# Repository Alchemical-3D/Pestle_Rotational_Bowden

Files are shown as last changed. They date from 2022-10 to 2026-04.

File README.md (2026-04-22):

<div align="center">

# 🥣 Pestle Rotational Bowden





*The flexible Bowden system designed to fit almost anywhere, while providing rotational movement to support even shorter Bowden assemblies.*

<p align="center">
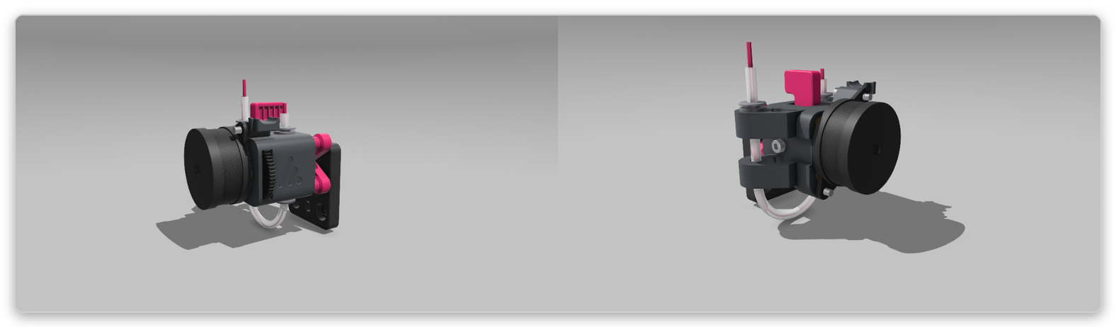
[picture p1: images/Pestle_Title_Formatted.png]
Bowden
  
</p>

**[Join the Discord!](https://discord.gg/aE49DW2xXe)**

</div>

<br>

---

## 📖 Preface

This is the Pestle Rotational Bowden.

The goal of this project is to provide an ultra-lightweight but powerful extruder which rides the X gantry (or anywhere else you wish) while also being able to rotate, allowing the shortest Bowden tube possible. The rotation removes the need for additional bend radii to get to the toolhead by providing a more direct route. 

Initial testing of this unit showed it was able to achieve a Bowden length of approximately <228.6mm, when the stock tube was near 508mm long. That is an improvement of 50%. On top of the PTFE length savings, the more direct filament route results in much lower PA values than traditional Bowden setups, as well as retraction settings which are more in line with Direct Drive. All of these benefits combined create a system that takes the best from each world without sacrificing overall performance.

The concept for this extruder was inspired by the now-defunct Voron Jetpack. We would like to extend a special thanks to the Voron team for their inspiration on this product. Please take a moment if you are not familiar with the Voron project to educate yourself on the hard work they commit to the makerspace: [https://vorondesign.com/](https://vorondesign.com/)

---

<p align="center">
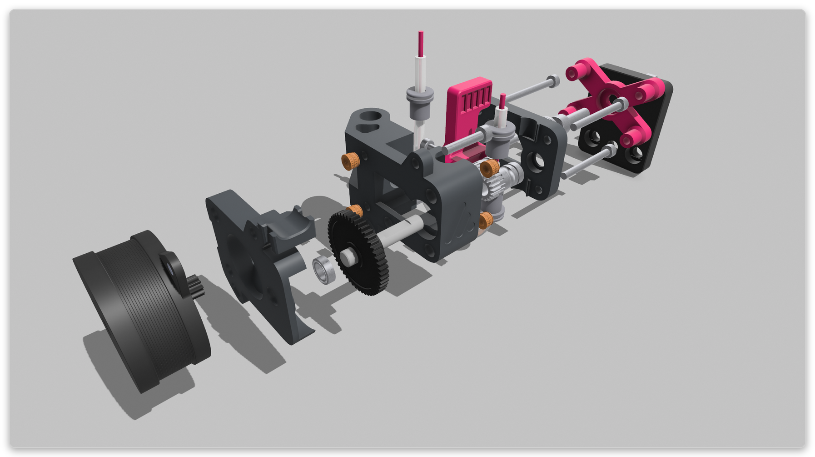
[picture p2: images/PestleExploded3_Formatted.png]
Bowden 2
  
</p>

---

## ⚙️ Print Settings

| Setting | Value |
| :--- | :--- |
| **Materials** | ABS/ASA *(Note: Parts account for shrinkage of ASA & ABS)* |
| **Layer Height** | 0.20 mm |
| **Extrusion Width** | Forced 0.4 mm |
| **Infill Percentage** | 40%+ |
| **Infill Type** | Grid, Honeycomb, Triangle, or Cubic |
| **Top/Bottom Wall Count** | 5 |
| **Perimeter Count** | 4 |

---

## 📋 Bill of Materials (BOM)

> [!NOTE]
> **Affiliate Links**
> Alchemical-3D has affiliate status with most of the links below. Purchases using these links help continue funding of the project. If you wish to configure a Pestle kit through a vendor (KB-3D) instead of sourcing individual parts, use this link [here](https://kb-3d.com/store/extruders-hotends/731-pestle-rotational-bowden-extruder-kit-beta-12-configurable-1670209967306.html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).
>
> *Note: This list is the bare minimum. It is wise to have spare screws, heat sets, etc.*

| QTY | Material | Notes |
| :---: | :--- | :--- |
| **7** | [M3x5x4 Heatsets](https://kb-3d.com/store/inserts-fasteners-adhesives/278-brass-heat-set-threaded-insert-for-plastic-m3x5x4mm.html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) | Angled exterior texture, not straight |
| **1** | [Thrust Bearing](https://kb-3d.com/store/magnets-bearings/696-5mm-x-12mm-x-4mm-thrust-bearing-f5-12m-1645908989939.html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) | 5mm ID x 12mm OD |
| **1** | M3x16mm SHCS | Socket Head Cap Screw |
| **1** | M3x20mm SHCS | Socket Head Cap Screw |
| **2** | M3x30mm SHCS | Socket Head Cap Screw |
| **2** | M3x35mm SHCS | Socket Head Cap Screw |
| **1** | M5x16mm SHCS | Socket Head Cap Screw |
| **1** | M5 Hex Nut | Standard M5 Hex Nut |
| **3** | [PC4-M6 Connector](https://kb-3d.com/store/inserts-fasteners-adhesives/707-push-fit-embedded-bowden-fitting-coupler-175-ecas04-1667064368065.html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) | Pneumatic Bowden Fitting |
| **1** | [BondTech BMG Internals Kit](https://kb-3d.com/store/bondtech/484-bondtech-bmg-extruder-internals-kit-build-your-own-1645151327973.html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) | Clones acceptable |
| **1** | [LDO Nema 14 High Temp Stepper Motor - 9T](https://kb-3d.com/store/stepper-motors-servos/4480-ldo-nema-14-high-temp-stepper-motor-36sth20-1004ahg-9t-for-g2-1640706862009.html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) | Pancake Stepper - Round |
| **1** | [Loctite 222MS Threadlocker](https://kb-3d.com/store/tools-equipment/774-loctite-threadlocker-222ms-low-strength-purple-mil-spec-6ml-1673749510419.html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) | Recommended Optional |

## ⚠️ Important Build Notes
> [!WARNING]
>
> If using **Threadlocker** (Loctite Blue or similar strength), please note that these can damage ASA/ABS when coming into contact. Take care when applying threadlockers to ensure they only contact the metal assembly parts.

> [!CAUTION]
> **Material Warning**
>
> This assembly comes in close proximity to a heated bed and stepper motor.  We do not support issues related to using PLA or other similar materials (PETG, PLA+, etc.).  These are **NOT** suitable to build 3D printer parts out of.

> [!WARNING]
> **Builder Responsibility**
>
> This is an aftermarket engineering project. You are solely responsible for your own safety and the integrity of your equipment when building and operating this system. By utilizing these files and instructions, you accept all liability.

---

## 🛠️ Assembly Guide

If you have questions regarding the location and orientation of each screw, heat set, and part you will require to assemble the Pestle extrusion system, please join the Discord and feel free to ask!

1. Locate each heat set location in the Pestle Extruder assembly; there should be a total of 6 heat sets required for assembly: (3) Main Body, (1) Lever, and (2) Transmission Plate. Heat your soldering iron to an appropriate temperature for the filament being used (near printing temp) and slowly press each heat set in squarely.
   > [!IMPORTANT]
   > The heat set in the main body that secures the lever **MUST** be inserted from the bottom of the body and remain flush with the bottom of the model. If this heat set is inserted from the top or improperly inserted, it may interfere with the lever's function.

2. Locate the (3) PC4-M6 locations. Two of these pieces will be added during assembly; the third can be added at any time. When adding the PC4-M6 fitting to the support arm, ensure it is being pressed in squarely, or the model can split. You may use a wrench or other flat object between the arm braces—place the fitting on a table and push down on it for easier insertion. Brute force may result in broken parts.

3. Insert (1) MR85ZZ bearing (included in the BMG kit) into the Top Plate and Bottom Plate of the extruder. A cutout has been made to allow a press-fit. These parts should be snug, but take care when inserting to keep components square and reduce the risk of cracking the model.

4. Slide (2) 5mm OD / 3mm ID needle bearing assemblies over (1) short 3mm bearing steel rod, and the secondary BMG drive gear over the top of the needle bearings. Snap the gear assembly into the printed Lever housing.

5. Insert (1) thumbscrew spring (included in the BMG kit; set aside the thumbscrew) into the inside of the main body. A recess has been made to house this spring, and once the lever is installed, it will be secure.

6. Verify alignment and use the printed lever arm to compress the spring as you insert it into the main body of the Pestle. Do not bend the main body at the lower supports, or it may break; use the main body section of the spring to pin the lever in place. Once in place, verify the filament path lines up with the teeth on the secondary BMG gear.

7. Slide the BMG primary gear over the BMG 50T 5mm primary drive gear and secure the grub screw to the flat section. A typical installation of the BMG gear sets it almost all the way down the shaft. Insert the back of the BMG drive gear into the bearing previously installed on the transmission plate.

8. Locate and install the transmission plate, Nema 14 stepper, and main body with the geared assemblies all at once. The stepper motor will hold the assembly together as the build continues. Do not worry about setting the stepper adjustments at this point.

9. Slide the top plate and bearing over the main body and gear assembly, and insert the final (2) PC4-M6 fittings between the top plate and the main body. Fittings must be added prior to fastening the top plate.

10. Add an M5x16 BHCS to the Rotational Cross Brace so that the threads stick out away from the top, with a thrust bearing (or shim washers) placed between the head of the bolt and the printed Rotational Cross Brace.

11. Add the rotational cross brace to the top of the Pestle extruder by fitting the (4) posts into the top plate's post holes. Secure the brace using (2) M3x30mm and (2) M3x35mm BHCS screws. The screws will pass through the entire assembly to the transmission plate and main body, respectively.

12. Add an M5 nut to your respective mounting solution and thread the Pestle assembly through it, with a thrust bearing placed between the rotational cross brace and the mounting solution.

13. *(Skip this step if not using PTFE in this manner)* Add PTFE Bowden tubing from the support arm looping under the extruder and into the bottom of the extruder. This acts as the reverse Bowden guide for the filament. Take care not to bend at too steep of an angle and kink the PTFE. If the PTFE is kinked and does not allow filament to pass smoothly, it should be replaced.

14. Add PTFE tubing from the top of the extruder to your toolhead assembly, then review the Pestle Retraction Settings below.

---

## 📏 Retraction Settings

| Setting | Value |
| :--- | :--- |
| **Retraction Distance** | 0.95 mm |
| **Retraction Speed** | 40 mm/s |
| **Detraction Speed** | 45 mm/s |
| **Estimated Pressure Advance** | 0.280 |
| **Estimated Pressure Advance Smooth Time** | 0.035 |

> [!NOTE]
> These settings are intended as a starting point for tuning and do not reflect all system requirements. Individual system needs vary, and your specific use case may require adjustments.

***

> ☕ **Did you find this guide helpful?** 
> 
> My projects are open-source and free for the community. If you've enjoyed my designs and want to support my work, consider [leaving me a tip on Ko-fi](https://ko-fi.com/alchemical3d)! 
>
> 

### [Visit our Discord!](https://discord.gg/aE49DW2xXe)

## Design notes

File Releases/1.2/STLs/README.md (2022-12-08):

# Filename Nomenclature

| Filename | Note |
|---|---|
| \*.stl | Base color |
| [a]\_\*.stl | Accent color |

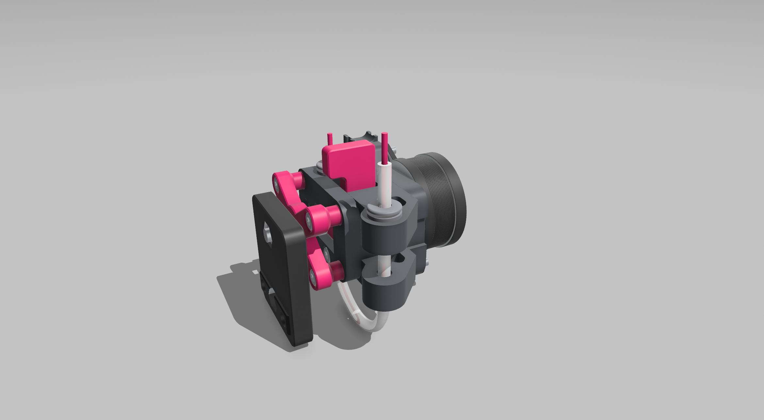
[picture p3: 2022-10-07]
images/Pestle3.png

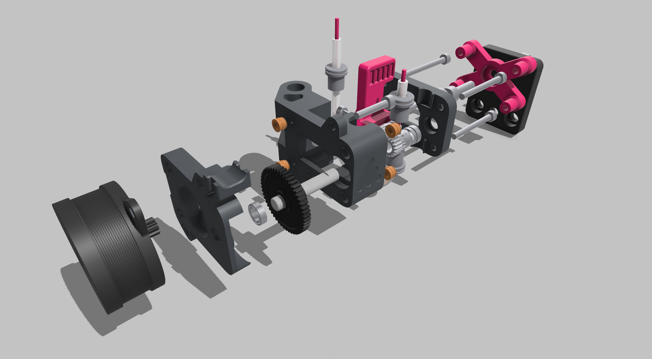
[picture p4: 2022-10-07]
images/PestleExploded3.png

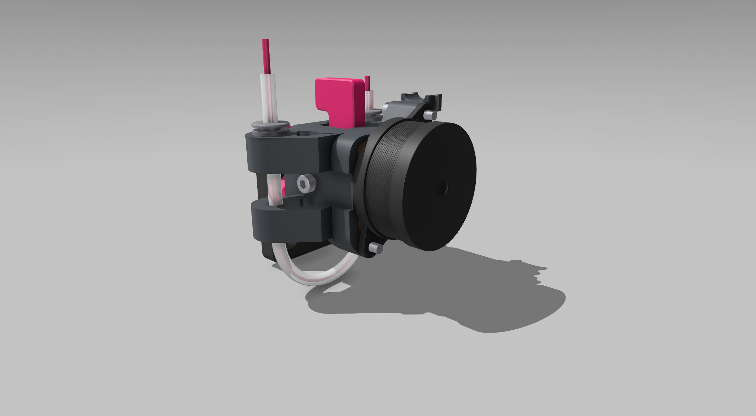
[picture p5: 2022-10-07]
images/Pestle2.png

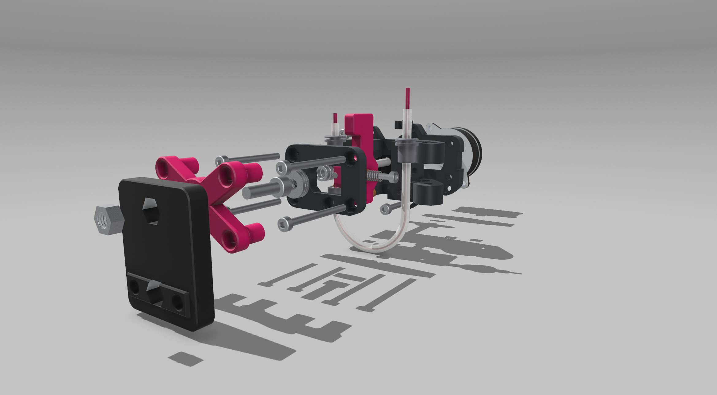
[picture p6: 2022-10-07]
images/PestleExploded5.png

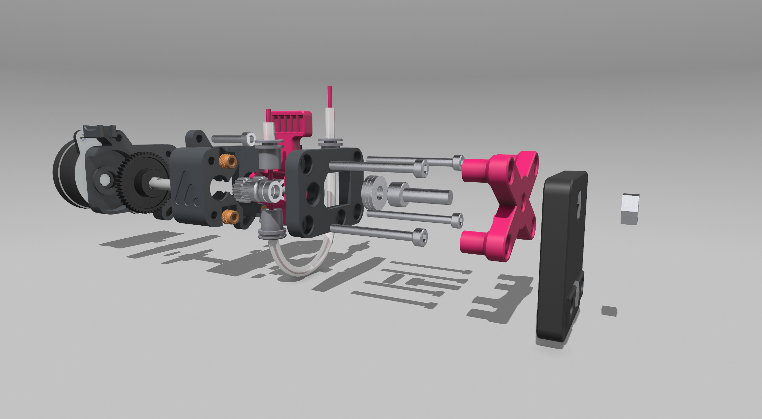
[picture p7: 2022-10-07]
images/PestleExploded1.png

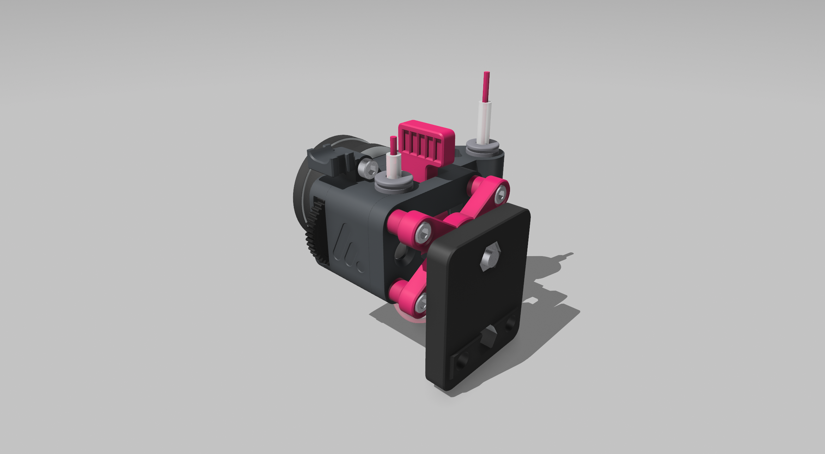
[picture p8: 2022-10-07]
images/Pestle4.png

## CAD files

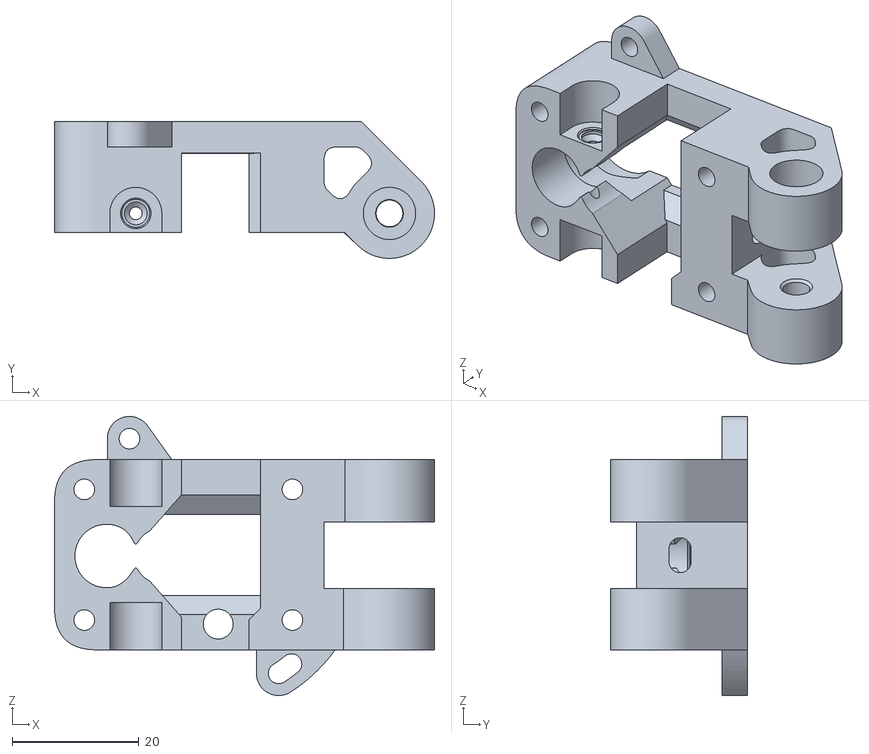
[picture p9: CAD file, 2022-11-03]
Releases/1.2/STLs/pestle_main_body.stl
59.9 x 21.6 x 44.0

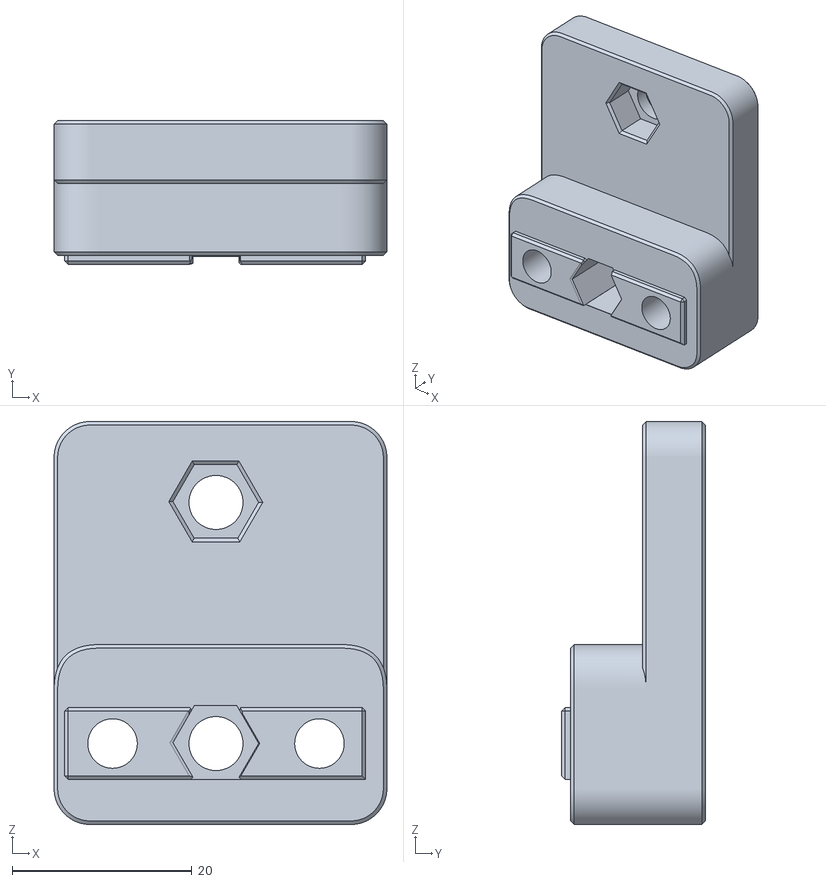
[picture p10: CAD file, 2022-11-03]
Releases/1.2/STLs/pestle_2020_extrusion_mount.stl
37.0 x 16.0 x 44.8

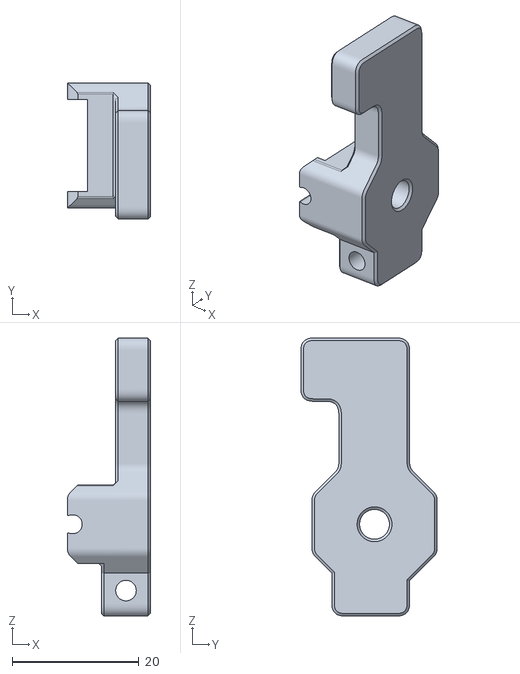
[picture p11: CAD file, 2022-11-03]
Releases/1.2/STLs/[a]_pestle_lever.stl
13.1 x 21.6 x 43.9

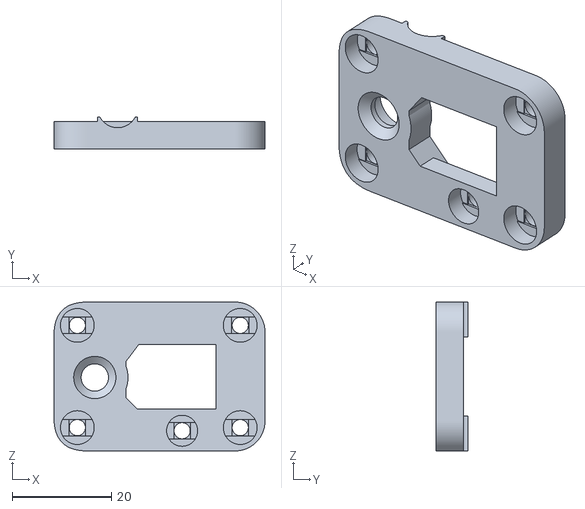
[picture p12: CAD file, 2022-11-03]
Releases/1.2/STLs/pestle_top_plate.stl
42.5 x 6.45 x 30.0

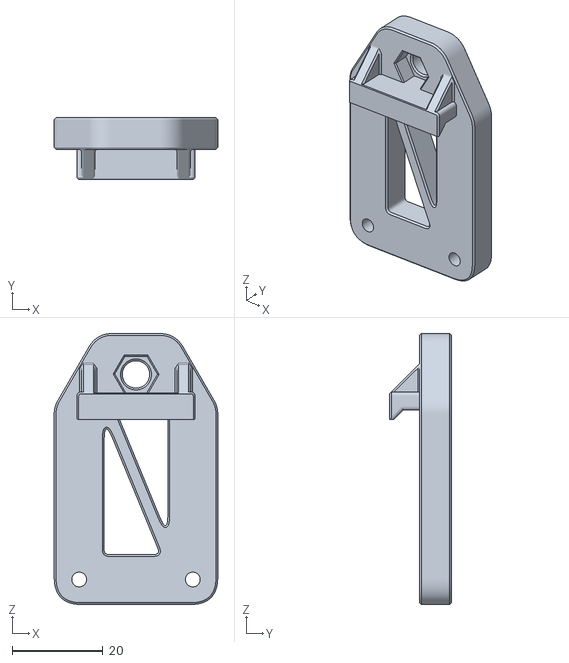
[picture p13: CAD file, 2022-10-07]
Releases/1.2/STLs/pestle_3DFused_gantry_mount.stl
36.0 x 13.6 x 59.6

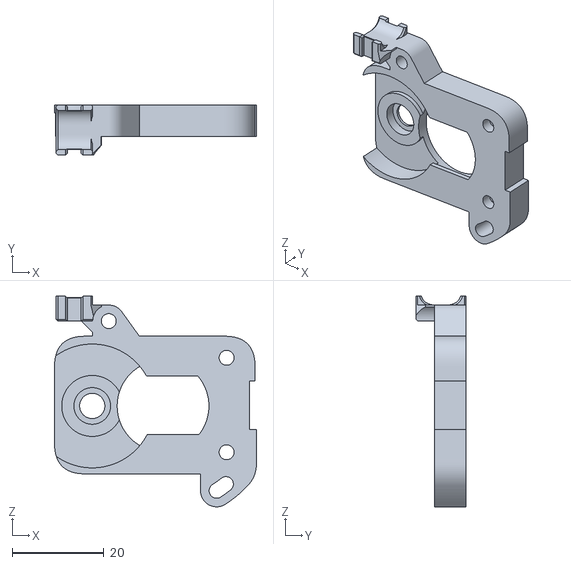
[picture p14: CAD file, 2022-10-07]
Releases/1.2/STLs/pestle_motor_plate.stl
44.0 x 11.0 x 45.9

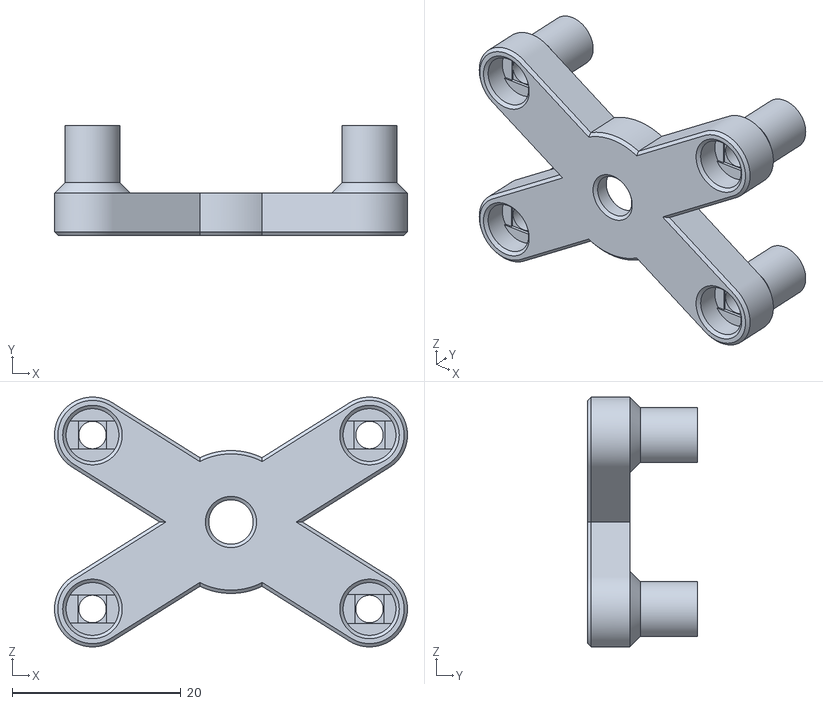
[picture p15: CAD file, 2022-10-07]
Releases/1.2/STLs/[a]_pestle_rotation_brace.stl
41.8 x 13.0 x 29.6

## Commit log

2022-08-25 Version 3.0
    Updates courtesy of Whatthefilament
    https://github.com/whatthefilament
    [Pestel_Rotational_Bowden.step, Pestle_Rotational_Bowden _v3.0 - Gantry Mount.step, Pestle_Rotational_Bowden _v3.0 - Gantry Mount.stl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]
2022-08-26 Printability Tweaks
    [Gantry Mount.step, Gantry Mount.stl, Lever.step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]
2022-09-03 Clearance Fix
    [Main Body -Plate.step, Main Body -Plate.stl, Pestel_Rotational_Bowden_Assembly.step]
2022-09-03 Clearance Update
    [Main Body -Plate.step, Main Body -Plate.stl, Pestel_Rotational_Bowden_Assembly.step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]
2022-10-07 Version Beta_7
    [Pestle parts - 2020_Extrusion_Mount.step, Pestle parts - 2020_Extrusion_Mount.stl, Pestle parts - 3DFused_Gantry_Mount.step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]
2022-11-03 Updated To Rev 1.2
    Greatly improved system tolerances, improved gear meshing, and reduced drive resistances.
    [Pestle_Rev-1.2 parts - 2020_Extrusion_Mount.stl, Pestle_Rev-1.2 parts - 3DFused_Gantry_Mount.stl, Pestle_Rev-1.2 parts - Lever.stl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]
2022-12-08 organizing files
    [Pestle_Rev-1.2 parts - 2020_Extrusion_Mount.step, Pestle_Rev-1.2 parts - 2020_Extrusion_Mount.stl, Pestle_Rev-1.2 parts - 3DFused_Gantry_Mount.step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]
2026-04-21 Update safety warnings in README
    Added warnings about material suitability and builder responsibility.
2026-04-21 Restore important build notes in README
    Reintroduced important build notes regarding material warnings and builder responsibility.
2026-04-21 Clarify material warnings in README
    Reword material warning for clarity and emphasis.
